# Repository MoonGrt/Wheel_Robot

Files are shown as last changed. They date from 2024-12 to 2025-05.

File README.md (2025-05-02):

**English | [简体中文](README_cn.md)**

[][contributors-url]
[][forks-url]
[][stars-url]
[][issues-url]
[][license-url]

<!-- PROJECT LOGO -->
<br />
<div align="center">
    <a href="https://github.com/MoonGrt/Wheel_Robot">
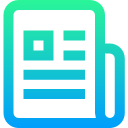
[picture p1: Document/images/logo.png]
    
    </a>
<h3 align="center">Wheel_Robot</h3>
    <p align="center">
    project_description
    <br />
    <a href="https://github.com/MoonGrt/Wheel_Robot"><strong>Explore the docs »</strong></a>
    <br />
    <a href="https://github.com/MoonGrt/Wheel_Robot">View Demo</a>
    ·
    <a href="https://github.com/MoonGrt/Wheel_Robot/issues">Report Bug</a>
    ·
    <a href="https://github.com/MoonGrt/Wheel_Robot/issues">Request Feature</a>
    </p>
</div>

<!-- CONTENTS -->
<details open>
  <summary>Contents</summary>
  <ol>
    <li><a href="#file-tree">File Tree</a></li>
    <li>
      <a href="#about-the-project">About The Project</a>
      <ul>
      </ul>
    </li>
    <li><a href="#contributing">Contributing</a></li>
    <li><a href="#license">License</a></li>
    <li><a href="#contact">Contact</a></li>
    <li><a href="#acknowledgments">Acknowledgments</a></li>
  </ol>
</details>

<!-- FILE TREE -->
## File Tree

```
└─ Project
  ├─ Document
  ├─ Software
  ├─ Tool
  └─ /Hardware/

```

<!-- ABOUT THE PROJECT -->
## About The Project

- [📦 Hardware System Design](#-Hardware-System-Design)
  - [🔋 Power Management Module](#-Power-Management-Module)
  - [🧩 FOC Driver](#-FOC-Driver)
  - [🐞 Link Debugger](#-Link-Debugger)
  - [🧲 Magnetic Encoder](#-Magnetic-Encoder)
- [🔧 Structural Design and Device Selection](#-Structural-Design-and-Device-Selection)
  - [🧱 Housing and Structure](#-Housing-and-Structure)
  - [⚙️ Power System](#-Power-System)
  - [🎯 Sensor Selection](#-Sensor-Selection)
- [💻 Software System Design](#-Software-System-Design)
  - [⚡ FOC Motor Control Subsystem](#-FOC-Motor-Control-Subsystem)
  - [🤖 ROS System Integration](#-ROS-System-Integration)
  - [🌐 Web Console](#-Web-Console)

### Hardware Selection

| Module | Component/Chip Model | Functional Description | Device Parameters |
| --- | --- | --- | ---|
| Master | Raspberry Pi | With ROS, responsible for SLAM algorithms | - |
| | STM32F405 | Dedicated to motor control (FOC, PID) | 180MHz, Cortex-M4 core |
| Sensors | AS5147P | Ultra-high-speed Magnetic Rotary Position Sensors | 16-bit resolution, SSI interface |
| | CMP10A | IMU Sensor | 3-axis gyroscope, 3-axis accelerometer, 3-axis magnetometer and barometer |
| | YDLIDAR X3 | LIDAR | 360° scanning, range 0.12-8m |
| POWER MANAGEMENT | LITHIUM BATTERY | - - | 24V, 3000mAh, XT60 socket |
| | TPS54160 + RT9193/LP5907 | 24V→12V/5V→3.3V Two-stage Buck Regulator | TPS54160-Buck, RT9193-VCC, LP5907-AVCC |
| | FSMD012 | Resettable Fuse - Overcurrent Protection | 50A Peak Current |
| | NCP18XH103F0 | Real-time monitoring of the circuit temperature, to prevent overheating damages | 10kΩ B-value -25°C /100°C-3455K |
| | LM5109B + RTP50W | High Speed Half Bridge Driver Control Dissipation Resistor | 5V-18V Driver + 50W Power Resistor, 2ohm |
| | SS34 | Schottky Diode | 3A, 40V, Low Dropout |
| | SMAJ26CA | TVS Diode, Surge Suppression Protection | 30V, Bi-Directional, 400W |
| | 1812 Capacitor × 10 | Decoupling Filter | 50V, 47µF, Ceramic Capacitor |
| Motor Driver | DRV8301 | Brushless DC BLDC Motor Driver Chip | 4.5V-60V, Peak Current 4A |
| | KNY3406C | Field Effect Tubes (MOSFETs) | Vds=40V, Id=60A, Rds(on)=6mΩ |
| | SG995 | Servo, Position Control | 180° Rotation Angle, Torque `13kg.cm @ 6V` |
| | PM3510 | Platform Brushless Motor | 1250rpm 0.11N.m |

### 📦 Hardware System Design

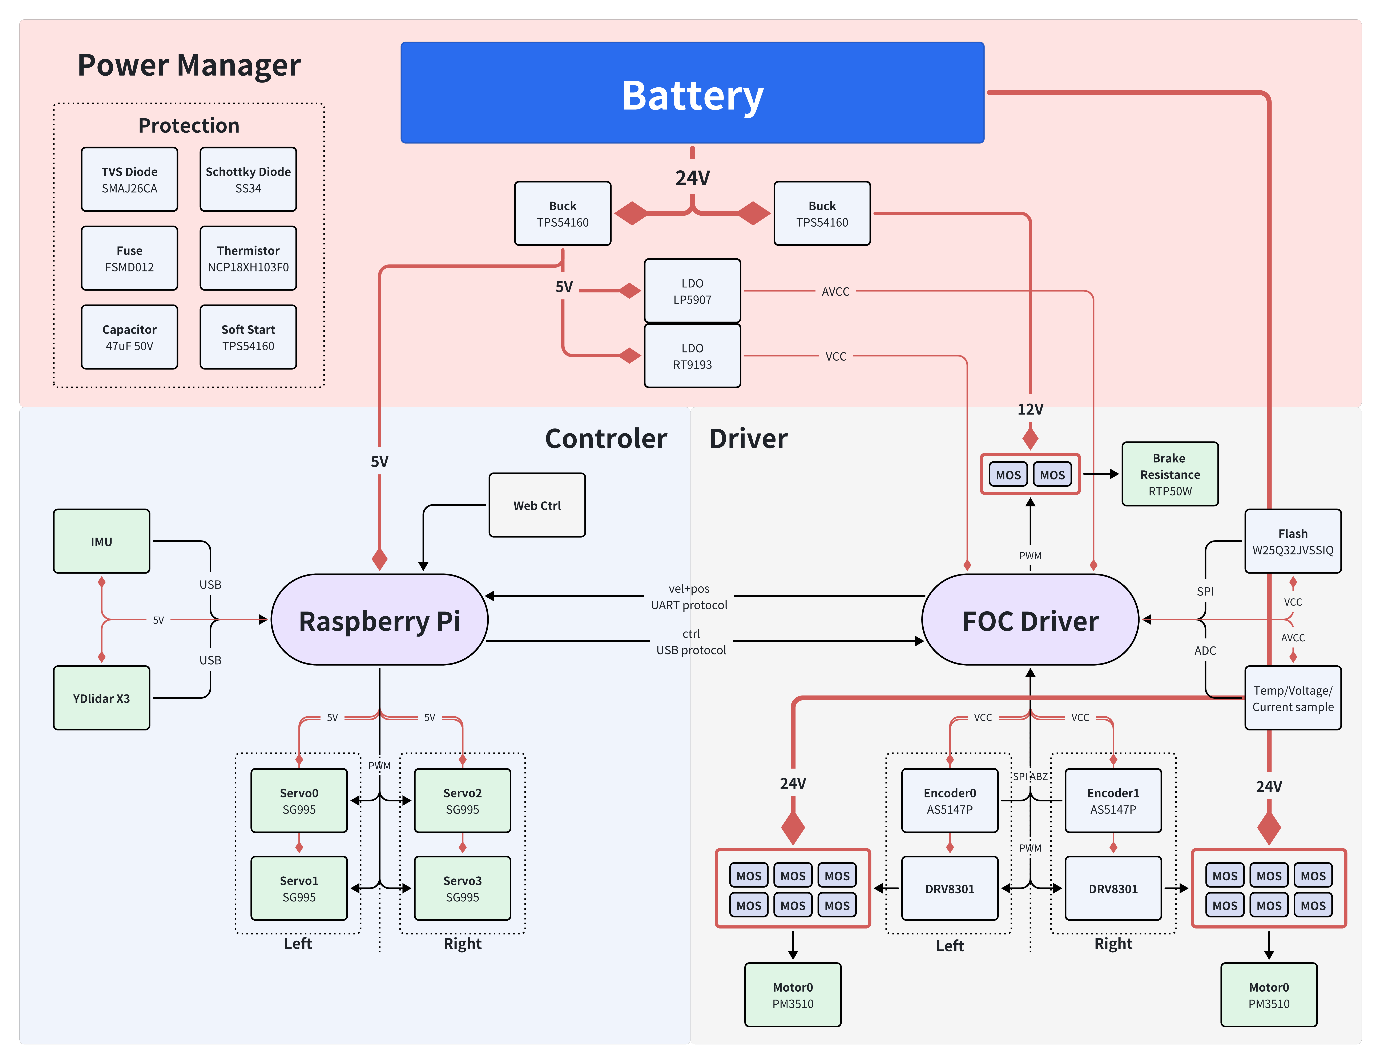
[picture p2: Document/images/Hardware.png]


#### 🔋 Power Management Module

The power management module distributes the battery energy, after buck regulator filtering, to the modules of Raspberry Pi, motor driver, sensors (IMU, Lidar, encoder), power system (BLDC motor, servo), etc., to ensure the power supply of each module operates stably.

- **Battery Management System (BMS)**
  - Uses **24V 3000mAh Li-ion battery pack** (XT60 interface) as the main power source.
    - 29.4V 2A charger
  - Built-in intelligent protection board for stable output and longer life:
  - Overcurrent protection: prevents the battery from discharging too much current
  - Short-circuit protection: the product is automatically protected in the event of a short-circuit
  - Over-voltage protection: prevents the battery from charging and discharging too high a voltage
  - Over-charging protection: prevents the battery from being over-charged
  - Over-discharging protection: prevents the battery from being over-discharged
  - Anti-backlash protection: stops the work automatically in case of reverse plugging
  - 10A Button Switch (main switch: for controlling battery charging/discharging; emergency disconnecting the battery) + 16AWG conductor
  - Soldering part is covered with insulating green oil + Heat-shrinkable tubing/insulation tape is used for connecting part of the conductor

- **Voltage Conversion**
  - **Two-stage Bucking Architecture**:
  - Power Supply 24V: Power supply the BLDC motors, BUCK step-down circuits, power supply voltage acquisition circuits, and other modules directly through the power MOS.
    - First stage: TPS54160 (24V→12V, power supply dissipative resistor; 24V→5V: power supply servo, Raspberry, LDO) (Output current 1.5A, switching peak limiting current 1.7~2.3A)
  - TPS54160 Configuration Reference [Texas Instruments Official Design Tools](https://www.ti.com.cn/ product/cn/TPS54160#tech-docs)
  - Stage 2: RT9193 (5V→3.3V, LDO linear regulator, VCC, power supply MCU, encoder chip, motor driver chip), LP5907 (3.3V→5V, voltage regulator, AVCC, power supply analogue end temperature sampling)
  - **Decoupling filter network**: 10 × 1812 ceramic capacitors (50V/47µF) + 1812 ceramic capacitors (63V/47µF)
  - Changing the capacitor closest to the TVS diode to 63V/47µF prevents the capacitor from breaking down due to the surge phenomenon during power-up.
  - **Isolated Ground** - The analogue/power ground is isolated from the digital ground to avoid signal interference.

- **Circuit Protection Design**
  - **Overcurrent Protection**: FSMD012 self-resetting fuse (48V/40A)
  - **Temperature Monitoring**: 10kohm NCP18XH103F0 thermistor (B-value -25℃/100℃-3455K)
  - **Reverse Connection Protection**: SS34 Schottky diode (40V/3A)
  - **Soft Start Protection **: TPS54160 soft-start setting pin external 6.8n capacitor (the larger the capacitance value, the slower the startup)
  - **Transient Suppression**: SMAJ26CA (reverse cutoff voltage (Vrwm): 26V; clamp voltage: 42.1V; peak pulse current (Ipp): 9.5A), bypass resistor (10Ω)
  - Previously used SMAJ30CA with clamp voltage was about 48.4V, the inrush current was so high that the voltage instantaneously rose above the capacitor breakdown voltage before the TVS reacted, causing the capacitor nearest the TVS to break down. (Battery output voltage is 24V~29V)
  - Previously used 3.3Ω resistor with limited inrush suppression
  - **LM5109B** High Speed Half Bridge Driver + **RTP50W** 2Ω/50W Dissipative Resistor to improve motor system stability.
    - Without power dissipation resistors, excess power is charged back to the supply during deceleration to achieve the desired deceleration torque. If the power supply is not able to absorb this energy (which is usually the case with battery power), the bus voltage will inevitably rise. This may cause damage to the switching power supply. In this design, although battery power is used, RTP50W dissipative resistors are still used to improve the stability of the motor system.
    - The power selection of the power resistor depends on your configuration of the motor and the peak power or average deceleration power generated when the motor decelerates. To be safe, you need to consider the speed of the motor and the current the motor can handle. When braking at maximum speed and maximum motor current, the power dissipated in the power dissipation resistor can be calculated as: P_brake = V_emf * I_motor where V_emf = motor_rpm / motor_kv. In this design, using a PM3510 motor with 1250rpm 45rmp/v 0.93A, P_brake = 1250 / 45 * 0.53 = 25.83W.

#### 🧩 FOC Driver

The dual motor FOC driver solution based on STM32F4 series microcontroller supports brushless motor vector control with integrated encoder interface, HALL sensors, CAN communication and multiple peripheral interfaces. It combines a powerful microcontroller with a dedicated driver chip to achieve accurate and highly responsive closed-loop control.

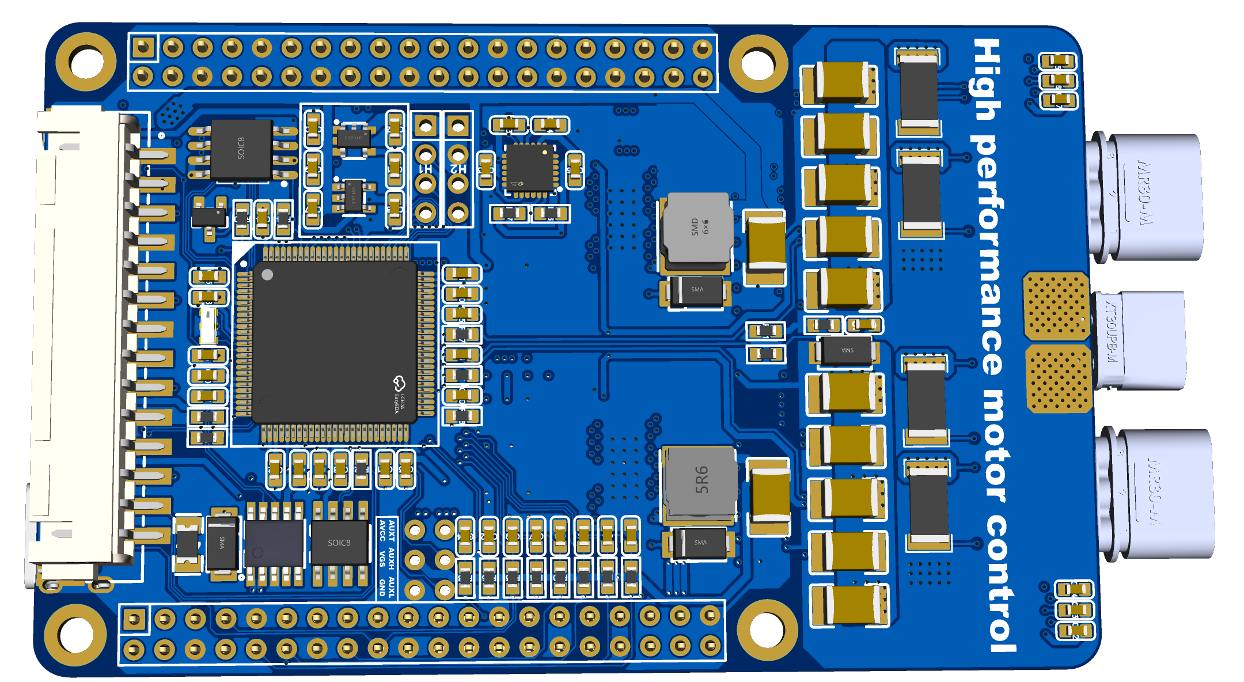
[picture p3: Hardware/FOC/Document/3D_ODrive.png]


- **Main Functional Modules**
  - **Master Control Unit**
    - **Kernel Chip**: STM32F405VGT6 (ARM Cortex-M4 core, 168MHz, 1MB Flash, 128KB SRAM)
    - **Clock System**: 8MHz Crystal Oscillator
    - **Debug Interface**: SWD (SWCLK/ SWDIO)
    - **Memory**: W25Q32JV SPI Flash
    - **Layer structure**: SIG-PWR-GND-SIG
      - Top layer: Signal layer + copper-laying GND
      - Inside layer 1: small amount of signals + copper-laying VCC
      - Inside layer 2: Power supply layer with copper-laying GND
      - Bottom layer: Signal layer with copper-laying GND
  - **Motor Driver Module**
    - **Driver chip**: DRV8301DCDC **: DRV8301DCAR × 2, support dual motor control
    - **Power Stage**:
      - Pre-Drive Circuit: KNY3406C MOSFET × 12
      - Current Sampling: 0.5mΩ Low Side Resistor
      - Provide Deadband Control, Programmable Gate Drive Capability
  - **Protection Design**:
    - SMAJ30CA TVS Diode
    - 2.2Ω Gate Drive Resistor
  - **Sensor and Feedback**
    - **Position Detection**:
      - Encoder Interface: ENC_A/B/Z signals
      - HALL Sensor Interface: GH/GL/SH/SL signals
    - **Temperature Monitoring**: M0_TEMP/M1_TEMP/AUX_TEMP thermistor interface
    - **Voltage Monitoring**:
  - **Communication Interfaces**
    - **CAN Bus**: SN65HVD232DR transceiver
    - **USB**: CH340K USB to Serial
    - **Expansion Interface**:
      - SPI: MOSI/MISO/SCK/CS
      - I2C: SCL/SDA
      - UART: TX1/RX2
  - **Power Management**
    - **Input Power**:
      - Battery Input: 24V DCBUS BUCK Buck circuit
      - USB power supply: Type-C interface
    - **Voltage regulator circuit**:
      - 3.3V LDO: LP5907MFX-3.3
      - 5V LDO: RT9193-33GB
  - **Filtering design**:
    - Multi-stage LC filtering
    - Ceramic capacitor array

- **Key design features**
  - **Dual-motor architecture**: two independent DRV8301 driver chips Enables dual FOC control
  - **Precision Sampling**:
    - 40nF differential capacitor for current sampling filtering
    - 18kΩ/133kΩ precision resistor network
  - **Safety Protection**:
    - NFAULT Fault Detection Circuitry
    - Dead Time Control (DTC=150kΩ)

- **Physical interface**

<div style="width: auto; display: table; margin: auto;">

| Interface Type | Function Description |
| ---|---|
| FPC-6 P | Download, Debug Interface |
| 2*20 row mother | Raspberry Pi Interface |
| Type-C | USB Communication |

</div>

- **PCB Design Features**
  - Layered Ground Plane: PGND (Power Ground)/AGND (Analogue Ground)/GND (Digital Ground) Separation
  - High Current Path: 1oz Copper Thickness 20~50mil Wide, Copper Cladding to Enhance Heat Dissipation
  - Test Points: TP1-TP6 for easy measurement of critical signals

- **Version**

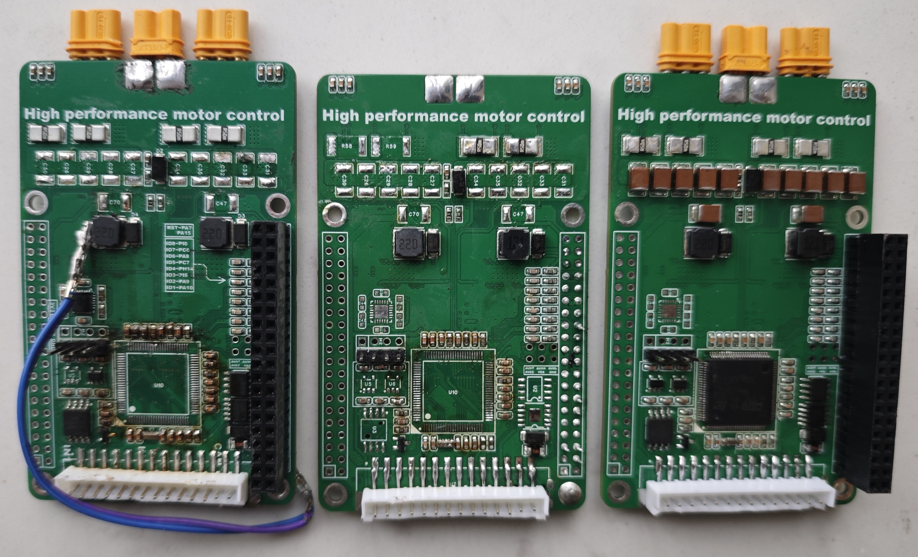
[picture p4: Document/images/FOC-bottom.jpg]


#### 🐞 Link Debugger
This circuit implements the debugger function based on STM32F103CBT6 microcontroller, compatible with STLink V2 and DAPLink firmware, supporting Type-C USB interface and SWD/JTAG debugging. Main purpose: miniaturisation (11mm x 26mm), portability (combining SWD and UART with FPC-6 interface, easy to connect the debugger to the master instead of connecting them one by one with Dupont cable).

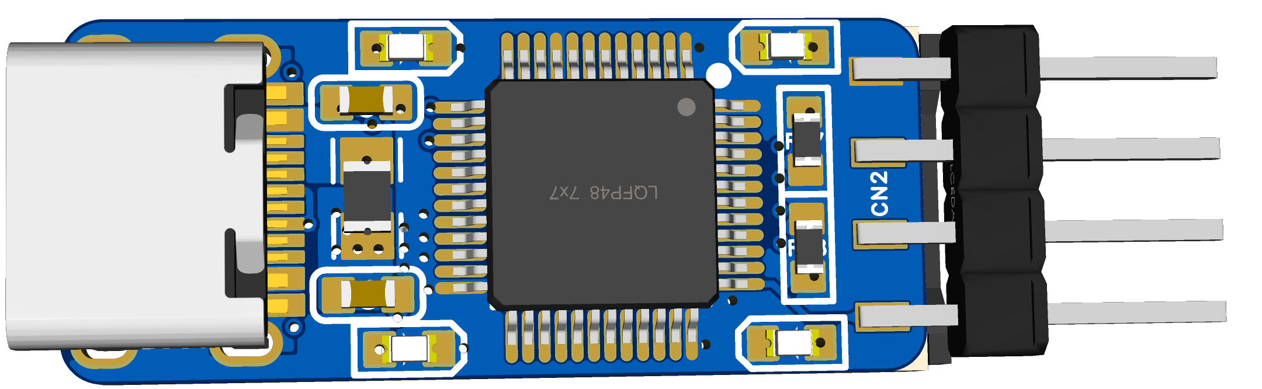
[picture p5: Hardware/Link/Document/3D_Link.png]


- **Main Module**
  - **Power Supply Module**
    - **LDO Circuit**: 5V to 3.3V (Model 662K)
    - **Filter Capacitor**: Input: 1µF; Output: 100nF
    - **Power Indicator**
    - **Power Supply Protection**: BSMD0805-100-6V, PPTC Self-Recovering Fuse for overcurrent prevention.
  - **Master Chip**
    - **Ctrl Unit**: STM32F103CBT6 (72MHz, 128KB Flash, 64KB SRAM)
    - **Clock Source**: 8MHz crystal with 22pF load capacitor
  - **Peripheral Circuitry**
    - **Reset Circuitry**: 10kΩ Pull-up Resistor + 100nF Filter Capacitor
    - **LEDs Indicator**: Power indicator, debug status indicator, serial communication indicator
    - **Power Acquisition**: Acquisition of half of the voltage value of the power supply to the ADC input to the MCU
  - **Connector**
    - **USB Interface**: Type-C USB interface
    - **FPC Interface**: 6Pin, UART+SWD interface,
    - **Debug Interface**: 4Pin SWD standard interface for firmware burning for debugger
- **Special Design**
  - **DTC143ZCA**: digital transistor: used to detect whether VBUS is valid or not, so as to control the USB_RENU signal
  - Resistors such as R10, R15, and R13 are used in conjunction with Q1, to form a simple voltage detection and pull-down control. When VBUS detects 5V, Q1 conducts and USB_RENU is pulled high (or low), prompting the MCU for ‘USB insertion detection’.

#### 🧲 Magnetic Encoder
Non-contact encoder with high precision magnetic rotary position sensor design, compatible with AS5147P, AS5047P, suitable for motor position detection, supports multiple output modes, with anti-interference and high temperature working characteristics.AS5147P comes with an LDO, so no extra LDO is needed.(Main function: connect/ (Main functions: connecting/welding encoder chip, supplying power to encoder chip - power protection, providing encoder interface to master control for connection)

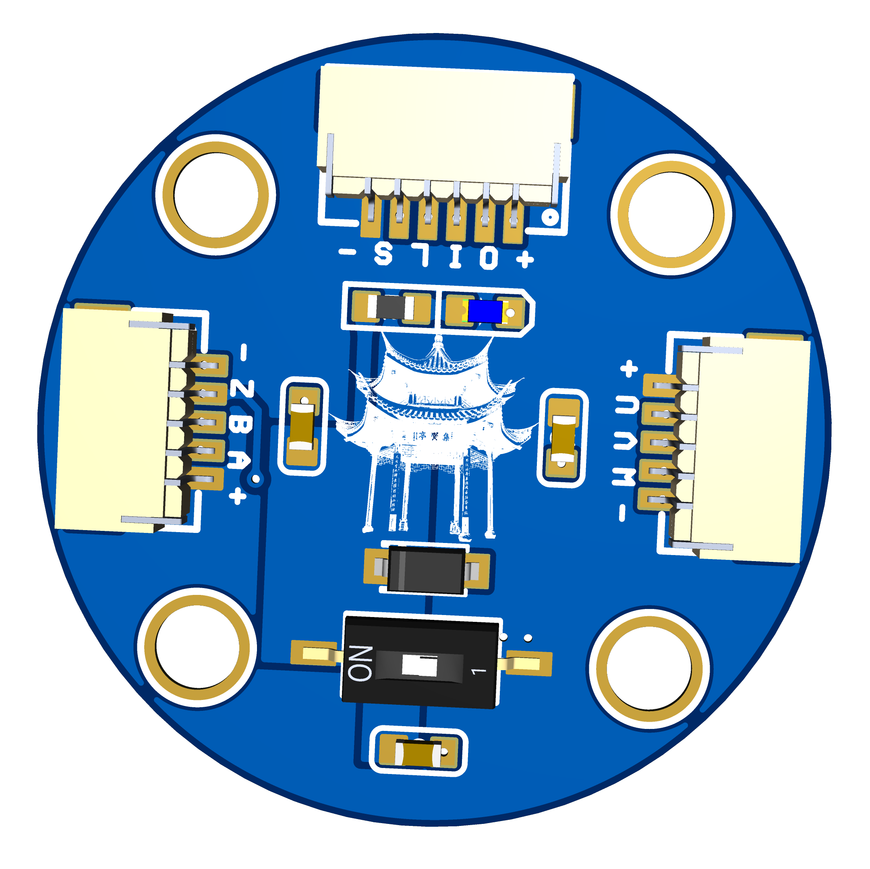
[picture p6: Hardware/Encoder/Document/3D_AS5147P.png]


- **Core Features**
  - **Resolution**: 14-bit absolute position output (0.022° accuracy)
  - **Interface Support**:
    - SPI (SCK/SDI/SDO/CS)
    - ABZ
    - UVW
    - PWM Pulse Width Modulation
  - **Operating Voltage**: 3.3V/5V Wide Voltage Compatible
    - Provide DIP switches for user to select input voltage mode
  - **Mechanical characteristics**: 360° contactless rotation detection
- **Hardware Design Points**
  - **Anti-Interference Design**
    - Power Filtering: 100nF ceramic capacitors in parallel
    - Signal Isolation: Magnetic Grids are laid out orthogonally to PCB alignment
  - **Protection Design**
    - SMFJ5.0A: Static and Surge Protection (TVS/ESD)
    - LEDs: Indicates the power supply status
  - **Size Design**: Combined with the Mechanical design, to be embedded in the housing, size 26mm

---

### 🔧 Structural Design and Device Selection

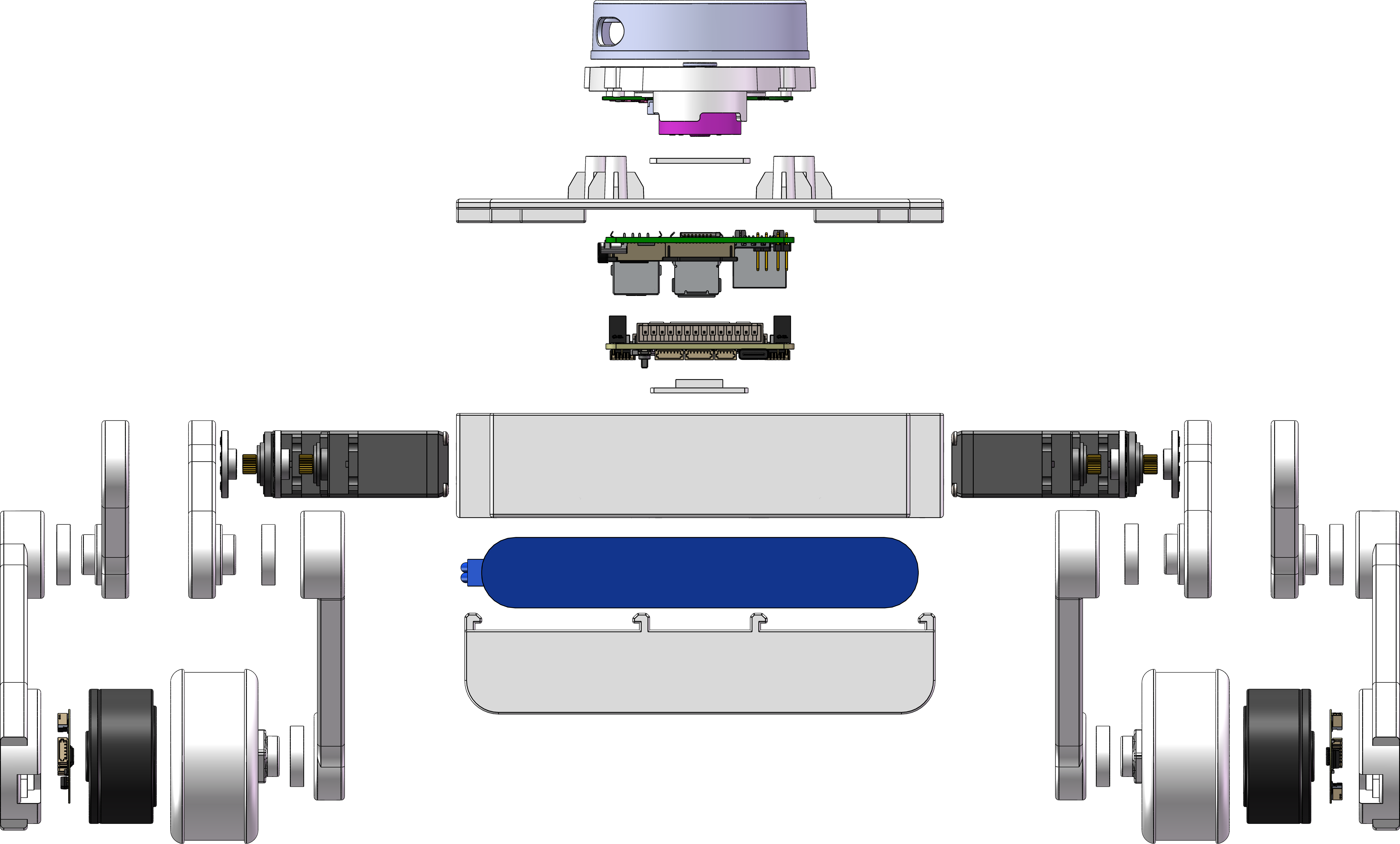
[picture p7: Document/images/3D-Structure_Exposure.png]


#### 🧱 Housing and Structure
- **3D printed housing**
  - Structure: modular assembly with quick release interface for easy maintenance and function expansion.
  - Internal reserved battery compartment, circuit board fixing holes, heat dissipation design.
  - Reserve 0.2mm tolerance between structural parts
  - Base:
    - Material: X resin (large parts, cost saving)
    - Thickness: 3mm
    - Structure:
      - Middle assembly tabs to fix the main control board and driver board
      - Fixed servos on both sides
      - Front and back openings to expose the main control board, driver board interface, and knob switch fixing holes.
      - Bottom: Sinking in the middle to fix the IMU module; both sides are reserved for the slots of the Battery Case.
      - Reserved threaded holes and countersunk holes for bolts
  - Cover:
    - Material: X resin (large part, cost saving)
    - Thickness: 3mm
    - Structure:
      - Base fixing holes
      - Assembly tabs to fix ydlidar, sunk in the middle to fix ydlidar driver board
      - Reserved threaded holes and countersunk holes for bolts
  - Battery Case:
    - Material: X resin (large part, cost saving) - Thickness: 3mm Cost saving)
    - Thickness: 3mm
    - Structure:
      - middle sunken to fix the battery
      - both sides partly upward to form the snap with Base
      - front and back right upper corner open hole, reserved for battery cable
      - reserved threaded holes, countersunk holes for bolts for connecting
  - Arm:
    - Material: PLA
    - Thickness: 8mm
    - Structure:
      - fix the servo and Motor Case
      - Arm inter-bearing connecting
      - reserved space for motor cables, encoder cables Space
      - Distance between control motor radial magnet and encoder (<1mm)
      - Reserved threaded holes, countersunk holes for bolts for connection
  - Motor Case:
    - Material: PLA
    - Thickness: 3mm
    - Structure:
      - Fixed Motor, Magnetic Encoder
      - Reserved space for bearings
      - Outer recessed, reserved space for rubber ring
      - Reserved threaded holes, countersunk holes for bolts for connection

#### ⚙️ Power System

- **Brushless DC motor**
  - Model: **PM3510**
  - Parameters: 1250rpm, 0.11N-m, 45 rmp/v, Driver chip DRV8301.
  - Note:
  - Motor radial magnet needs to be replaced (the original motor radial magnet has a poor magnetism, which results in a noisy encoder).
    - When installing a stronger encoder magnet, the distance between the magnet and the encoder in the mechanical design should be considered.
- **Servo**
  - Model: **SG995**
  - Parameters: 20ms, 180°rotation angle (500-2500), 13kg-cm Torque (@6V), 100mA.
  - Note:
    - Pay attention to the initial angle when installing, to avoid the wrong rotation direction.

#### 🎯 Sensor Selection

##### **AS5147P High-Speed Rotary Position Sensor**

- **Product Overview**
  - **AS5147P** is a CMOS technology-based 14-bit, high-resolution, axial-magnetic rotary position sensor designed for high-speed applications up to **28,000 RPM**, providing complete ** 360° absolute angle measurement**. It incorporates advanced **Dynamic Angular Error Compensation (DAEC™)** technology, which effectively suppresses angular errors caused by system delays to achieve a virtually **zero delay output**.
  The AS5147P also features a **12-bit incremental binary output interface (ABI)** with a resolution of up to **4096 steps/1024 pulses per revolution**, which is suitable for encoder systems. Through the standard **4-wire SPI interface**, the master device can read the high-precision angular information output from the sensor, and supports programmable non-volatile configurations without the need for an external programmer.

- **Key features**

  <div style="width: auto; display: table; margin: auto;">

  | Feature Category | Description |
  |--------------------|-------------------------------------------------------------|
  | **Resolution** | 14-bit Absolute Angle-SPI<br>12-bit Incremental Encoding (ABI: 1024/2048/4096) |
  | **Speed Support** | Up to **28,000 RPM** for high speed rotation detection |
  | **Output Interfaces** | SPI, ABI, UVW commutation signals, PWM Duty Cycle encoded outputs |
  | **Dynamic Angle Compensation** | DAEC™ Dynamic Angle Error Compensation (for SPI, ABI, UVW outputs, enhancing real-time) | | **Dynamic Angle Compensation** | DAEC™ Dynamic Angle Error Compensation (for SPI, ABI, UVW outputs, enhancing real-time) |
  | **Anti-Interference Capability** | Suppresses uniform stray magnetic field interference and improves system stability |
  | **Non-Volatile Configuration** | SPI interface programmable, no need for dedicated programmer |
  | **Self-Diagnostic Functions** | Detects magnetic field strength abnormalities (too strong/too weak/absent), device status abnormalities, etc. |
  | **Interpolation and Signal Integrity** | Interpolates missing ABI pulses at high speeds to ensure resolution and signal continuity. Interpolation and Signal Integrity**| Interpolates missing ABI pulses at high speeds to ensure resolution and signal continuity.

  </div>

  - **Technical Principles and Architecture** 
    - The AS5147P utilizes an array of **Hall effect sensors** that convert magnetic field components into voltage signals by sensing the magnetic flux density perpendicular to the chip surface. After amplification and filtering by an analog front end (AFE), these signals are fed into an analog-to-digital converter (ADC) and then processed by the CORDIC algorithm to accurately calculate the angle and amplitude of the magnetic vector. In addition, the AS5147P 
      - **Automatic Gain Control (AGC)** mechanism: real-time adjustment of the front-end gain to adapt to changes in magnetic field and temperature 
      - **CORDIC Algorithm Module**: calculates the angle of rotation and the amplitude of the magnetic field 
      - **Interpolation Mechanism**: completes the missing pulse of the ABI at high speeds to ensure the continuity of the output signals 
    - The AS5147P has a **Dynamic Angular Error Compensation (DAEC™)** function. The AS5147P features **Dynamic Angle Error Compensation (DAEC™)**, which improves real-time performance of the SPI, ABI, and UVW outputs by estimating the time delay during angle measurements and predicting and compensating for the angular output error accordingly. This compensation is particularly effective at constant speeds.

##### **YDLIDAR X3 LIDAR** 

The YDLIDAR X3 is a high-performance, compact 2D LiDAR (LiDAR) product that utilizes the principle of triangulation and combines advanced optical, electrical and algorithmic design to enable **360-degree omni-directional environmental scanning and high-precision distance measurement**.

- 🌐 Core Functions Overview 
  - 🔄 **360° Omni-directional Scanning and Distance Measurement** 
  YDLIDAR X3 is equipped with a rotary motor, which is capable of realizing **complete 360-degree rotations in the horizontal plane**, and real-time outputting the distance measurement data of the corresponding angle in each rotation to form a high-density 2D point cloud map. This means that it is capable of **panoramic perception of its surroundings** and can obtain complete spatial information without moving the platform itself.
  - 🎯 **High-precision and high-frequency ranging performance** 
  The radar achieves a ranging capability of up to **4,000 times per second** (typical) through the mechanism of transmitting high-frequency laser pulses and receiving them as echoes, ensuring smooth, detailed perception even in fast-moving environments.
    - **Typical ranging accuracy: ±2cm (≤1m)** 
    - **Relative error: minimum 1%, and within 3.5%~5% at long distances** 
  - ☀️ **Strong resistance to interference from ambient light** 
  The YDLIDAR X3 possesses good resistance to interference, and can work stably under natural light or artificial light. Whether it is bright daylight exposure or indoor lighting strobe, it can maintain stable output to ensure the reliability of ranging data.
  - 🔋 **Low power consumption, small size, long life** 
  The product design focuses on energy saving and portability, with low energy consumption operating characteristics, and adopts a long-life rotating structure and optoelectronic components, which is suitable for long-term deployment in a variety of smart devices.
  - ⚙️ **Motor speed is adjustable to suit different needs** 
  Users can adjust the scanning frequency from **5Hz to 10Hz** according to the application needs, balancing the measurement accuracy and real-time performance. For example: 
    - **5Hz: the angular resolution can be up to 0.6°**, suitable for scenarios requiring high accuracy (e.g. map building) 
    - **10Hz: the angular resolution is 1.2°**, which is more suitable for tasks requiring higher real-time performance (e.g. obstacle avoidance) 

- ⚙️ Performance Parameters

  <div style="width: auto; display: table; margin: auto;">

  | Item | Minimum | Typical | Maximum | Unit | Remarks | 
  | ------------------ | -------- | -------- | -------- | ------ | ---------------------------- | 
  | Ranging Frequency | / / | 4000 | / | Hz | Ranging per second max. 4000 times | 
  | Scanning Frequency | 5 | 8 | 10 | Hz | Motor Adjustable | 
  | Ranging Range | / | 0.12/8 | / | m | 10%/80% Reflective | 
  | Scanning Angle | / | 0-360 | / | ° | Rotation of 360° | 
  | Absolute Error of Ranging | / | 2 | / | cm | ≤1m range | 
  | Relative Error | / | 1% | 5% | / | Maximum Relative Error in 8m distance | 
  | Angle Resolution | 0.6 | 0.96 | 1.2 | ° | corresponds to 5Hz/8Hz/10Hz respectively | 
  | Pitch | 0.25 | 1 | 1.75 | ° | Bound Angle control range |

  </div>

##### **CMP10A-IMU Inertial Measurement Unit**

CMP10A is a high performance 3D motion attitude measurement system based on MEMS technology. It contains three-axis gyroscope, three-axis accelerometer, three-axis electronic compass motion sensor and barometer. Through the integration of various high-performance sensors and the use of self-developed attitude dynamics core algorithm engine, combined with high-dynamic Kalman filter fusion algorithms, to provide customers with high-precision, high-dynamic, real-time compensation of the three-axis attitude angle, through the flexible choice of configuration of various types of data, to meet the different application scenarios.

- **Product Features**
  - The module integrates high-precision gyroscopes, accelerometers, geomagnetic field sensors and barometers, and adopts a high-performance microprocessor and advanced dynamics solving and Kalman dynamic filtering algorithms, which are able to quickly solve the current real-time motion attitude of the module.
  - The advanced digital filtering technology can effectively reduce the measurement noise and improve the measurement accuracy.
  - Module internal integrated attitude solver, with dynamic Kalman filtering algorithm, can accurately output the current attitude of the module in the dynamic environment, attitude measurement accuracy of static 0.05 degrees, dynamic 0.1 degrees, the stability is very high, the performance is even better than some professional inclinometer.
  - The Z-axis heading angle is fused with geomagnetic sensor filtering, which solves the cumulative error caused by the drift of the gyroscope integral in the 6-axis algorithm, and can output the heading angle data stably for a long time. Note: It needs to be calibrated before use due to magnetic field detection, and it needs to be kept at least 20cm away from magnetic interference areas, electronic devices, magnets, speakers and other hard magnetic objects.
  - Module comes with internal voltage stabilisation circuit, working voltage 3.3~5V, pin level compatible with 3.3V/5V embedded systems, easy to connect.
  - Supports both serial and IIC digital interfaces. Convenient for users to choose the best way to connect. Serial rate 4800bps~921600bps adjustable, IIC interface support full speed 400K rate.
  - Maximum 200Hz data output rate. Output content can be freely selected, output rate 0.2 ~ 200Hz adjustable.

- **Sensor parameter indicators**

  <div style="width: auto; display: table; margin: auto;">

  | Sensor Type | Parameters | Conditions | Typical |
  | ------------ | ------------ | -------------------- | -------------------------- |
  | Accelerometer | Range | | ±16g |
  | | Resolution | ±16g | 0.0005 (g/LSB ) |
  | | RMS Noise | Bandwidth = 100Hz | 0.75~1 mg-rms |
  | | Stationary Zero Drift | | Horizontal Positioning | ±20~40 mg |
  | | Temperature Drift | -40°C ~ +85°C | ±0.15 mg/°C |
  | | Bandwidth | | 5~256 Hz |
  | Gyro Gauge | Range | | ±2000 °/s |
  | | Resolution | ±2000 °/s | 0.061 (°/s)/LSB |
  | | RMS Noise | Bandwidth=100Hz | 0.028~0.07 (°/s)-rms |
  | | Stationary Zero Drift | Horizontal Placement | ±0.5~1 °/s |
  | | Temperature Drift | -40°C ~ +85°C | ±0.005~0.015 (°/s)/°C |
  | | Bandwidth | | 5~256 Hz |
  | Magnetometer | Range | | ±2 Gauss |
  | | Resolution | ±2 Gauss | 0.0667 mGauss/LSB |
  | Barometer | Range | | 300~1100 hPa |
  | | RMS Noise | Standard Mode | 0.5 Pa-RMS |
  | | Relative Accuracy | | ±0.06 hPa |

  </div>

#### **structural connections**
bearings rolled tape insulating tape wires conductors bolts nuts rubber rings (tyres) 502 glue

---

### 💻 Software System Design

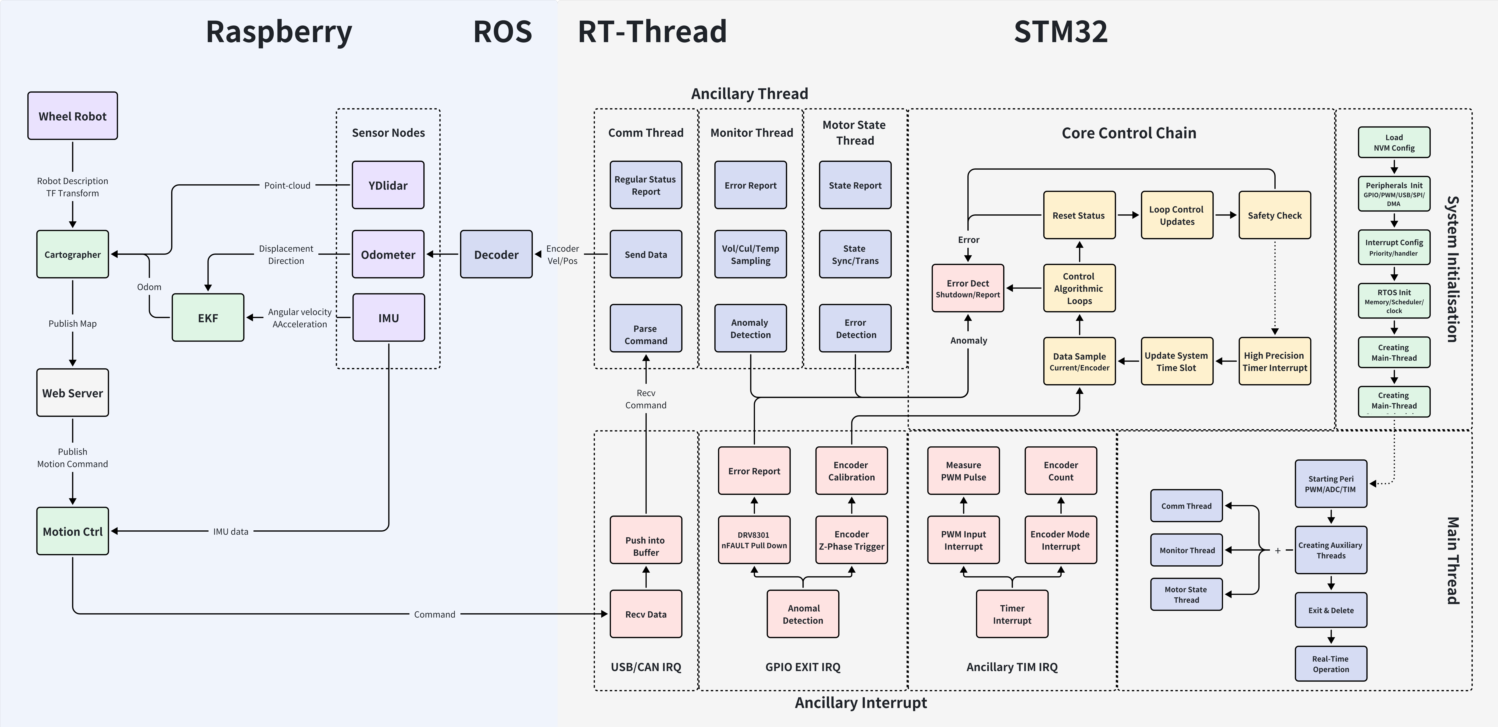
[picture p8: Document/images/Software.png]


#### ⚡ FOC Motor Control Subsystem

##### RT-Thread RTOS
Realisation of task isolation: control thread, current sampling thread, communication thread run independently;

```mermaid
graph TD

    A[System boot] --> B[Load configuration parameters in NVM]
    B --> C[System initialisation]
    C --> C1[Initialise peripherals<br>GPIO/PWM/USB/SPI/DMA...]
    C --> C2[Interrupt Configuration<br>Priority Setting/Register Handler Functions/Initiate Interrupts]
    C --> C3[RTOS Initialisation<br>Memory/Scheduler/Clock...]

    C3 --> D[create main thread]
    D --> E[start scheduler]
    E -.-> F[Main thread execution]
    F --> F1[Start peripherals<br>PWM/ADC/TIM]
    F1 --> F2[Create auxiliary thread]
    F2 --> F2a[Communication processing thread]
    F2 --> F2b[System monitoring thread<br>Analog acquisition/status monitoring]
    F2 --> F2c[Motor status management thread]
    F2 --> G[Exit and delete main thread]

    G --> H[enter real-time running state]

    %% Real-time thread section
    subgraph Real-time running status
        H1[Communication thread]
        H1 --> H1a[Periodic status report]
        H1 --> H1b[USB/CAN interrupt receive command]
        H1 --> H1c[UART polling receive command]
        H1b --> H1d[Receive and parse external control command]
        H1c --> H1d
        H1d --> H1e[Update control target]
        H1c --> H1f[UART polling to send data<br>motor speed/position]

        H2[Monitoring thread]
        H2 --> H2a[Acquire system status<br>temperature/voltage/error signals]
        H2a --> H2b[Abnormality detection]

        H3[Motor status thread]
        H3 --> H3a[Periodic refresh<br>status information for each axis]
        H3a --> H3b[Synchronise current control state<br> operating mode/feedback variables]
        H3b --> H3c[Forward error messages]
    end

    %% Control Chain (driven by hardware timers & interrupts)
    subgraph Control Chain Execution - Core Timer Interrupts
        T1[High Precision Timer Interrupt<br>Control Cycle Trigger] --> T2[Updates System Time Slot]
        T2 --> T3[Software Triggered Control Interrupt<br>Scheduling Control Calculation Flow]
        T3 --> T4[Trigger Sampling & Data Acquisition<br>Current/Encoder /sensor data]
        T4 --> T5[Execute real-time control algorithm loop<br>position/velocity/current]
        T5 --> T6[Reset state & check safety conditions]
        T6 --> T7[Execute closed-loop control update<br>State estimation/PID tuning/PWM update]
        T7 --> T8[Verify cycle integrity/safety check]
        T5 -->|Anomaly detection| D1[interrupt trigger protection<br>shutdown/error reporting]
        T8 -->|anomaly detection| D1
    end

    %% Auxiliary Interrupt
    subgraph Auxiliary Interrupt
        U1[USB/CAN communication interrupt]
        U1 --> U2[Receive command data]
        U2 --> U3[Write data queue]

        G1[GPIO EXIT interrupt]
        G1 --> G2[Detect fault signal]
        G2 --> G3[DRV8301 Fault interrupt... <br>nFAULT pull down...] --> G3a[power down/up error]
        G2 --> G4[encoder Z phase interrupt<br>] --> G4a[encoder calibration] --> T4

        E1[auxiliary TIM interrupt]
        E1 --> E2[encoder interrupt] --> E2a[record encoder edge] --> T4
        E1 --> E3[PWM capture interrupt] --> E3a[read PWM signal Width] --> T4
    end

    %% Interlink
    H1e --> T5
    H2b -->|Exception Feedback| D1
    H3c -->|Error Feedback| D1
    G3a -->|DRV8301 Failure| D1
    U3 -->|Instruction Queue| H1b

    %% Style definitions
    classDef init fill:#CDEDF6,stroke:#2B7A78,color:#17252A;
    classDef thread fill:#E6F7D9,stroke:#4CAF50,color:#1B5E20;
    classDef runtime fill:#FFF3CD,stroke:#FFC107,color:#7F4E00;
    classDef control fill:#E1D5E7,stroke:#9C27B0,color:#4A148C;
    classDef interrupt fill:#FFE5B4,stroke:#FF9800,color:#E65100;
    classDef error fill:#FADBD8,stroke:#C0392B,color:#641E16;

    %% Category labelling
    class A,B,C,C1,C2,C3,D,E init
    class F,F1,F2,F2a,F2b,F2c,G,H,H1,H2,H3,H1a,H1b,H1c,H1d,H1e,H1f,H2a,H2b,H3a,H3b,H3c thread
    class T1,T2,T3,T4,T5,T6,T7,T8 control
    class U1,U2,U3,G1,G2,G3,G3a,G4,G4a,E1,E2,E2a,E3,E3a interrupt
    class D1 error
```

- 🟦 **Initialisation phase**
  - Starting from `System Startup`:
  - **Load Configuration Parameters from NVM**: Used to load previously saved system parameters such as motor configurations, calibration data etc.
  - **System initialisation**: divided into three key sections:
    - `GPIO/PWM/USB/SPI/DMA` and other peripherals initialisation.
    - Interrupt configuration, including interrupt priority setting, registering ISR.
    - RTOS (Real-Time Operating System) initialisation, starting the scheduler, memory stacks, etc.
  - Finally, creating the main thread and starting the scheduler.
- 🟩 **Main thread running logic**
  - **Starting peripherals**: e.g. PWM outputs, current sampling ADCs, timers, etc.
  - **Create three auxiliary threads**:
    - **Communication processing threads**: USB/CAN/UART receive, status upload.
    - **System monitoring threads**: such as temperature, voltage monitoring and fault detection.
    - **Motor status management thread**: periodic update of the operating status of each axis.
  - The main thread exits when the task is completed and the system enters the real-time operation state.
- 🟨 **Real-time operation phase**
  - **Communication thread (H1)**
    - Handles USB/CAN/UART commands.
    - Report status data.
    - Parses control commands, updates control targets, and enters the control chain (associated with the control core).
  - **System Monitoring Thread (H2)**
    - Periodically collects temperature, voltage, error flags, etc. Performs anomaly detection.
    - Performs anomaly detection and reports to `Error Handling D1` when problems are found.
  - **Motor Status Management Thread (H3)**
    - Periodically refreshes motor status and feeds back to the control system.
    - Transmits operating mode changes, error messages, etc.
- 🟪 **Core Control Chain**: This is the ‘heart’ of the control system, driven by the timer interrupt:
  - High-precision timer interrupt triggered → control cycle starts.
  - Start the soft interrupt to execute the control logic:
    1. **Sampling data**: Read encoder, current sensor, etc. 2.
    2. **Execute control algorithm**: including closed-loop control of position, speed, current.
    3. **Update PWM**: output to motor drive.
    4. **Cycle safety check and status reset**.
  - If an abnormality is detected, it will immediately enter `Error Interrupt Processing` and shutdown/protection.
- 🟧 **Auxiliary Interrupt Module**: interrupt events that supplement the control logic:
  - **Communication Interrupts**
    - Receives USB/CAN external control data, writes it to the command queue, and later parses and executes it by the communication thread.
    - UART DMA interrupt
  - **GPIO interrupt**
    - Detects e.g. `DRV8301 nFAULT` fault signal.
    - Z-phase encoder interrupt for one-time calibration (e.g., home alignment).
  - **Timer interrupt**
    - Encoder edge capture, PWM width capture for RPM and position measurement.

- Note:
  - Note why the thread performs the control and uses a timer interrupt?

##### PID Regulation Flow - FOC Algorithm

The control algorithm uses a three-level closed-loop architecture with position control, speed control and current control in order from top to bottom. The control thread receives new input commands, reads the encoder and current sensor feedback, executes each level of the PID algorithm, and updates the control output in each control cycle. The entire process is embedded with measures such as anti-integral saturation, limiting, gain scheduling, and anti-groove calibration to ensure high accuracy and robustness.

- **Overall flow of the control chain**
  ```mermaid
  graph LR
    A[Incoming target command from host computer<br>Position/Speed/Current] --> B[Input processing & trajectory planning<br>Multi-mode filtering/Trap Traj / Mirror etc.]
    B --> C[Position Loop: compares the target position with the current encoder or estimate and calculates the positional error]
    C --> D[Generate additional speed expectations based on P-control and anti-alveolar compensation etc.]
    D --> E[Speed loop: compare desired speed from position loop with actual speed to calculate torque or current expectations using PI structure]
    E --> F[Conversion: torque expectation is calculated from motor output via PI structure speed expectation]
    D --> E[Velocity loop: compare desired speed from position loop output with actual speed<br>Calculate torque or current expectation using PI structure]
    E --> F[Conversion: torque expectation is converted to current expectation by motor parameters and torque constants<br>ACIM-type motors need to be scaled by flux]
    F --> G[Current Loop: access to the d-q coordinate system, control current error using the PI algorithm PI algorithm to control current error]
    G --> H[Voltage command calculated and converted by SVPWM module to generate PWM waveform]
  ```

  Of these:
  - **Input Processing** Updates the internal setpoint according to the different input modes (Passthrough, speed/torque ramping, trajectory planning, etc.) and filters the loop bandwidth, limits, etc.
  - **Position loop** In position control mode, only proportional feedback (pos_gain) is used in conjunction with loop drift correction, notch compensation, etc.
  - **Velocity loop** In addition to multiplying the velocity gain (vel_gain) to obtain a preliminary torque command, an integral term (vel_integrator_torque_) is introduced for error accumulation, and windproof control (gain scheduling and anti-saturation measures) is used.
  - The **current loop**, on the other hand, performs PI modulation of the d-q current error within the Field Oriented Control module, with the integral state limited by the saturation condition of the modulation vectors and combined with feed-forward terms (e.g., reverse potential, R/L feed-forward) to guarantee the system response.

- **Schematic of control chain operation**
  The interaction between the control thread and the peripherals and ADC/FOC interrupts can be summarised as:

  ```mermaid
  sequenceDiagram 
    participant host computer 
    participant communication thread 
    participant control thread 
    participant ADC/FOC interrupt 
    participant encoder 

    host computer->>communication thread: sends target commands (JSON / other formats) 
    communication thread->> Control thread: update input setpoints (position/velocity/torque) 
    Control thread->>Encoder: get position, velocity data (including PLL or encoder estimation) 
    Control thread->>Control thread: preprocessing, trajectory planning according to input mode 
    Control thread->>Control thread: [Position Loop] calculate position error, update vel_ setpoint Control thread->>Control thread: [Position loop] calculate position error, update vel_ setpoint Control thread->>Control thread: [Position loop] calculate position error, update vel_ setpoint setpoint 
    Control thread->>Control thread: [Velocity loop] Calculate velocity error, accumulate acceleration integral, generate torque (current) expectation 
    Control thread->>ADC/FOC interrupt: update current setpoint to FOC module 
    ADC/FOC interrupt-->>Control thread: collect feedback current, trigger current loop PI regulation (FOC) 
    ADC/ ADC/FOC interrupt-->>PWM driver: Generate PWM waveform according to the voltage command from FOC module.

  ```

  In this process:
  - **Input Processing**: not only includes direct setpoint transmission, but also includes various logics such as filtering, slope updating, Trap Traj interpolation, mirror mode, etc.
  - **Feedback from each link**: Position and speed errors affect low and medium frequency control respectively, while the current loop operates at higher frequencies to ensure timely response of the entire closed loop.
  - **Error protection and monitoring**: Sensor validity, limit status and power mismatch are constantly detected inside the control thread, and protection is triggered in case of abnormality (e.g. shutdown or error reporting).

- **Position loop** PID (slow closed loop)
  - **Inputs**: target position (pos_setpoint) vs. actual position (encoder / PLL or sensorless estimation).
  - **Outputs**: generation of a correction value for the target velocity (vel_setpoint).
  The position loop is often purely proportional (P-control), and should cycle the cyclic setpoints. In some modes, anti-groove calibration data is also superimposed on the error correction.

  ```cpp
  // Note: the actual code distinguishes between linear and cyclic setpoints,
  // and introduces both drift prevention and gain scheduling (which reduces the feedback gain when the error is small).
  float pos_error = pos_setpoint - pos_estimate;
  if(config_.circular_setpoints) {
      pos_error = wrap_pm(pos_error, pos_wrap_value);
  }
  vel_setpoint = vel_setpoint_base + config_.pos_gain * pos_error;
  ```

- **Speed loop** PID (medium speed closed loop)
  - **Inputs**: desired speed generated by the position loop (with position P compensation), actual speed (from encoder / PLL output).
  - **Output**: calculation to obtain a torque expectation, which is converted to represent the current (iq_setpoint).
    The implementation uses a PI control structure, where the integral term is protected against saturation (e.g. limiting or attenuation). The sample code concept is shown below:

  ```cpp
  float vel_error = vel_desired - vel_estimate;
  vel_integrator_torque_ += (vel_integrator_gain * vel_error * dt);
  vel_integrator_torque_ = std::clamp(vel_integrator_torque_, -config_.  vel_integrator_limit, config_.vel_integrator_limit);
  // Here it is also possible to combine gain scheduling: lowering the P-action at small errors (gain_scheduling_multiplier)
  float torque = torque_setpoint + (vel_gain * gain_scheduling_multiplier * vel_error) + vel_integrator_torque_;
  ```

  Among them:
  - **Input modes**: different modes (e.g. VEL_RAMP, TRAP_TRAJ, MIRROR, TUNING, etc.) determine how the pos_setpoint/vel_setpoint/torque_setpoint is updated;
  - **Limiting mechanism**: ensures that the system output does not exceed the safe range by limiting the torque and vel_ setpoint to ensure that the system output does not exceed the safe range;
  - **Error detection**: triggers an error condition immediately when, for example, overspeed error or spinout (electromechanical power mismatch) is detected.

- **Current loop** PID (FOC control, high speed closed loop)
  - **Inputs**: target current (iq_setpoint and (optionally) id_setpoint) and measured current (Iq, Id sampled by ADC and transformed by Clarke / Park).
  - **Output**: Voltage command in d-q coordinate system calculated by PI control (including feed-forward term), then converted to PWM waveform by inverse Park transform and SVPWM algorithm. The sample code concept is as follows:

  ```cpp
  // Take the Iq component as an example (Id generally holds or tracks a predetermined value, depending on the algorithm and motor type)
  float Ierr_q = iq_setpoint - iq_measured;
  v_current_control_integral_q_ += Ierr_q * (i_gain * dt);

  // If overmodulation is detected (output vector amplitude exceeds limits), the integration term is attenuated (protection against integration storms)
  float mod_scalefactor = /* Scaling factor calculated from current output modulus */;
  if (mod_scalefactor < 1.0f) {
      // Lockout or decay points
      v_current_control_integral_q_ *= 0.99f;
  }
  vq = Vq_feedforward + (p_gain * Ierr_q + v_current_control_integral_q_);
  ```

  This is followed by an inverse Park transform and SVPWM algorithm similar to the one below:

  ```cpp
  // Convert mod_d, mod_q in d-q coordinates to α-β coordinates.
  float c_p = cos(pwm_phase);
  float s_p = sin(pwm_phase);
  float mod_alpha = c_p * mod_d - s_p * mod_q;
  float mod_beta = c_p * mod_q + s_p * mod_d;

  // SVM module maps (mod_alpha, mod_beta) to PWM timings (tA, tB, tC)
  auto [tA, tB, tC, success] = SVM(mod_alpha, mod_beta);
  ```

  - Note: The current control state is used for feedforward and load prediction in the actual control, taking into account R/L and feedforward compensation of the reverse electromotive force, which is reflected in the code in Motor::update() and FieldOrientedController::get_alpha_beta_output().

  > **Additional Notes**:
  > - All the PID parameters for each link (e.g. pos_gain, vel_gain, vel_integrator_gain, current loop p_gain, i_gain, etc.) are loaded from the NVM during system initialisation, and parameter tuning directly affects closed-loop dynamics and stability.
  > - In addition, the input modes (e.g. TRAP_TRAJ for trajectory planning mode) and anticogging measures are also preprocessed at the setpoint before the PID control chain, thus ensuring smooth and robust control instructions.

##### Driver Development
- **Encoder (ASA5147P)**: supports multiple types including: SPI, ABI, UVW, PWM; this motor driver supports two modes:
  - ABZ mode: uses the encoder mode of the stm32F4 timer peripheral, reads the position and speed feedback from the motor encoder
  - SPI mode: directly reads the ASA5147P's registers with higher 14-bit precision
- **FLASH (W25Q32JVSSIQ)**: for storing parameters, configurations, etc.;
- **Motor Driver (DRV8301)**
  - SPI Initialisation, Configuration Chip
  - Using stm32F4 advanced timer TIM1 TIM8: for 3-phase motor drive, reducing EMI; Complementary PWM output with dead time configuration (force PWM to be 50% during count down) to prevent short-circuiting of the upper and lower bridge arms straight through
- **Servo Driver (SG995)**: PWM mode of TIM2 to control the servo's angle.

##### Communication protocols
- **USB CDC/HID** **CAN bus**
  - fibre stack: a set of application layer protocols used for communication between the upper and lower units. The corresponding communication protocol stack is generated according to the contents of the ymal file.
  - Data type: format of packet Format of stream
- **UART Serial port**: to communicate with external sensors or Raspberry Pi.
  - Serial communication protocol: UART 921600 8N1, ASCII format; sends motor position and speed information continuously at 100Hz.

##### Configuration Tool UI
- **Parameter Configuration Tool**
  - QT-based visualisation interface;
  - Visual parameter tuning: motor pole-pair number, encoder CPR, brake resistance settings ......;
  - One-click calibration: measurement of the motor's electrical characteristics (i.e., motor phase resistance and phase inductance), as well as encoder offset calibration;
  - Real-time monitoring : Voltage, current, temperature feedback.
  - **Note**: The platform brushless motor used in this project is
- **PID Configuration Tool**: further unleash the performance of the FOC driver board. By adjusting the PID parameters, the controller can quickly respond to disturbances or changes in the system (e.g., applied external forces or changes in setpoints) without becoming unstable, which ensures that the motor driver board is able to control the motor in the most efficient way.
  - QT-based visualisation interface;
  - Real-time monitoring: position and speed feedback;
  - Sliders: visual adjustment of the PID parameters;
  - **Experience**: first set the Ki of the speed loop to 0 and the Kp of the position loop to a relatively small value. Gradually increase the Kp of the velocity loop by about 30% per iteration until the motor vibrates. In reality, as Kp increases, the current sound gets louder and louder and eventually vibrates at high frequency. Back off the Kp of the velocity loop to 50% of the vibration value and then set the integrator to 0.5 * bandwidth * vel_gain, where bandwidth is the total tracking bandwidth of the system. For this project, bandwidth was 10 hz. set the Ki of the velocity loop = 0.5 * 10 * vel_gain according to the formula. subsequently, gradually turn up the position loop Kp until some overshoot is seen. Back off the position loop Kp until there is no more overshoot. Debugging can be done by giving a Kp and then a position target to see the step response.
  - **Note**: Tests have found that the magnitude of the current sound has nothing to do with the Kp of the position loop, and everything to do with the Kp of the velocity loop; reduce the velocity loop Kp, and the current sound will be much smaller. It is reasonable to say that the larger the Kp of the position loop, the more overshoot, but actually found that the Kp is relatively small, the motor is very soft, at this time instead of overshoot. I feel that because the motor is too soft at this time, to the target position is a little out of control.

---

#### 🤖 ROS System Integration

##### 🧪 Simulation Platform Construction
The SLAM simulation platform is built first, which facilitates rapid algorithm verification and parameter debugging. The capacity of the physical battery is limited, and it is easy to damage to affect the project progress.

- **URDF**: robot model structural modeling;
  - **sw_urdf_exporter tool**: https://github.com/ros-industrial/sw_urdf_exporter
    - coordinate parameterization of solidworks modeling, use the tool sw_urdf_ exporter to convert the results to URDF format;
    - difficult to simulate a wheel-footed robot directly, here it is simply converted into a two-wheeled differential model for testing;
    - the tool will automatically calculate the mass and moment of inertia based on the model material and generate the corresponding STL file.
  - **Wheel_Robot**: base_link, laser_link, imu_link, left_wheel_link, right_wheel_link
    - base: fixed imu, laser_link, 8 arm (simplified model) : fix the arm directly on the base, can't move up and down
      - Mass: 0.459 kg, the main part of the robot.
      - Inertial origin: at (-0.00238, 0, 0.0969), probably due to design center of gravity shift.
      - Geometry and collisions: both defined using the base_link.STL file.
    - laser:
      - mass: 0.0866 kg, lightweight design.
      - Mounting position: fixed to base_link at (-0.0005, 0, 0.1246) by laser_joint.
      - Function: LIDAR sensor on top of the robot.
    - imu:
      - mass: 0.00216 kg, very light.
      - Mounting position: Fixed to base_link at (-0.01, 0, 0.0946) by imu_joint.
      - Function: Inertial measurement unit, near the center of the base, for attitude detection.
    - wheel:
      - Mass: about 0.01686 kg, symmetric design.
      - Geometry and collision: both use left_wheel_link.STL and right_wheel_link.STL.
      - Mounting position:
        - Left wheel: (0, 0.0655, 0.02596), rotating around y-axis (axis="0 1 0").
        - Right wheel: (0, -0.0655, 0.02596), rotating around the y-axis in the negative direction (axis=“0 -1 0”).
        - Wheel spacing: 0.174 m (symmetrically distributed on both sides of base_link).

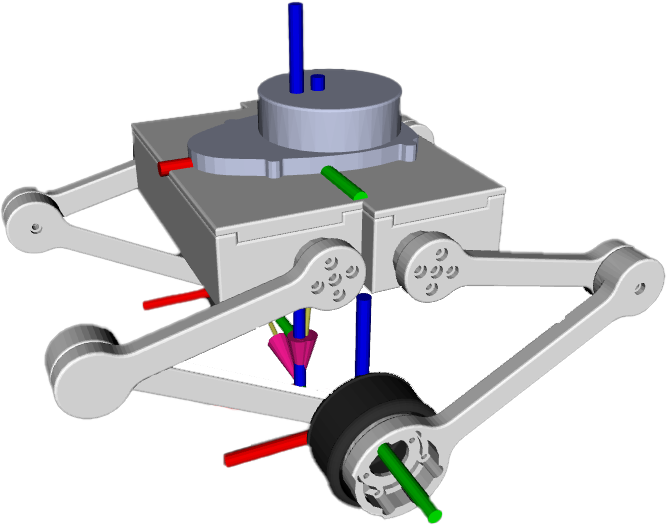
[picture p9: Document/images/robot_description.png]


- **Gazebo**: to realize the full simulation environment;
  - **gazebo plugin**: to add the plugin to the generated urdf plugin in order to generate the sensor data that the simulation environment allows to be needed;
  - **1. Differential Drive Plugin (`diff_drive`)**: to realize the differential drive control with the odometer release.
    - **Wheel_separation**: `0.174 m`
    - **Wheel_diameter**: `0.026 m`
    - **Maximum Torque & Acceleration**: `20 N-m` and `1.0 rad/s²` for small robots but need to be adjusted according to actual motor performance.
    - **TF Publishing**: `publish_odom_tf` is set to `true` to make sure the `odom` → `base_link` coordinate transformation is working.
  - **2. Joint state publishing plugin (`joint_state`)**: publish left and right wheel joint states to `/joint_states`.
    - **Update frequency**: `30 Hz`, consistent with the differential drive plugin, reasonable.
    - **Joint names**: correctly associate `left_wheel_joint` and `right_wheel_joint`, matches URDF.
    - **TF Publishing**: robot_state_publisher node runtime publishes coordinate transformations for `base_link` → `left_wheel_link` and `base_link` → `right_wheel_link`.
  - **3. IMU Sensor Plugin**: configures IMU sensors and publishes IMU data.
    - **Noise model**: add Gaussian noise for both angular velocity and linear acceleration to match the real IMU characteristics.
      - **Angular velocity noise**: standard deviation `2e-4 rad/s`, slight jitter, reasonable.
      - **Linear acceleration noise**: standard deviation `0.017 m/s²`, deviation mean `0.1 m/s²`, simulated zero-bias drift, consistent with low-cost IMU characteristics.
    - **Update frequency**: `100 Hz`, meets most SLAM algorithm requirements.
    - **TF Publishing**: robot_state_publisher node runtime publishes `base_link` → `imu_link` coordinate transformations.
  - **4. laser radar (LiDAR) plugin**: configure LiDAR and publish LiDAR data.
    - **Scanning parameters**: 360° scanning, `1°` resolution, `3.5 m` maximum range, `0.12 m` minimum, for indoor environments.
    - **Noise**: Gaussian noise (`stddev=0.01 m`), analog measurement error, reasonable.
    - **Publishing frequency**: `5 Hz`, low, may affect the real-time obstacle avoidance, it is recommended to upgrade to `10-20 Hz`.
    - **Installation position**: <pose>`0 0 0.075 0 0 0</pose> 0`, offset relative to `laser_link` needs to be superimposed with the actual height of the LIDAR in the URDF (`z=0.1246 m`) to ensure that the final position is correct.
    - **TF Publishing**: robot_state_publisher node runtime publishes the `base_link` → `laser_link` coordinate transformation.
  - **Simulation Scenarios**:
    - Scenario 1: [willowgarage](Software\ROS\wheel_robot_sim\src\wheel_robot\worlds\willowgarage.png)
      - Willow Garage The office environment is a classic simulation scenario used to testing robot navigation, SLAM and human-robot interaction algorithms.
    - Scenario 2: [cafe](Software\ROS\wheel_robot_sim\src\wheel_robot\worlds\cafe.png)
      - Cafe World is a simulation of a cafe scene designed to test robot navigation, SLAM and human-robot interaction algorithms in a dynamic environment.
    - Compare the two

        <div style="width: auto; display: table; margin: auto;">

        | **Features** | **Willow Garage** | **Cafe World** |
        |------------------------|---------- -------------------|-----------------------------|
        | **Scene Types** | Office Environment | Service Scene (Cafe) |
        | **Dynamic Elements** | Static Obstacle Oriented | Dynamic Pedestrians + Movable Objects |
        | **Testing Focus** | Navigation, SLAM | Human-Computer Interaction, Obstacle Avoidance | | **Complexity** | Medium (structured layout) | High (lots of dynamic interference) |

        </div>

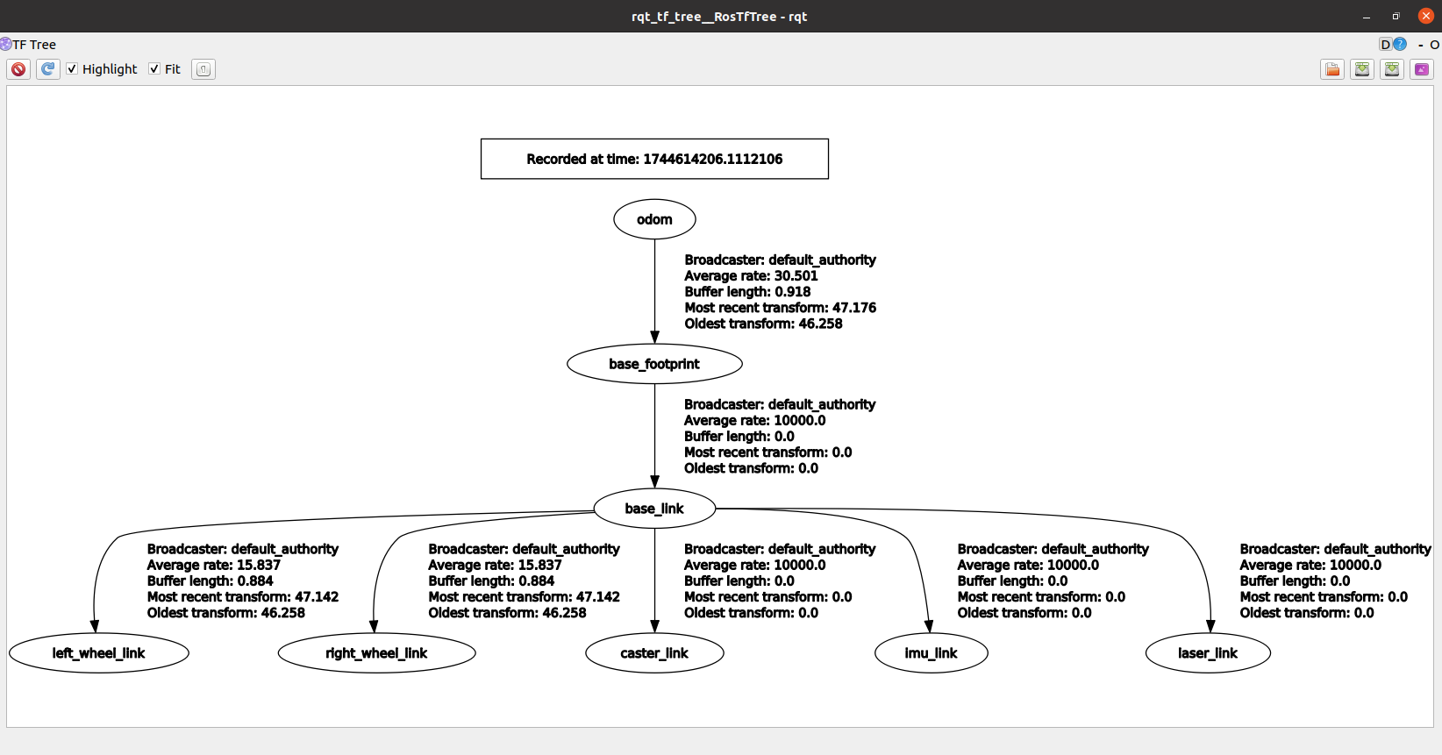
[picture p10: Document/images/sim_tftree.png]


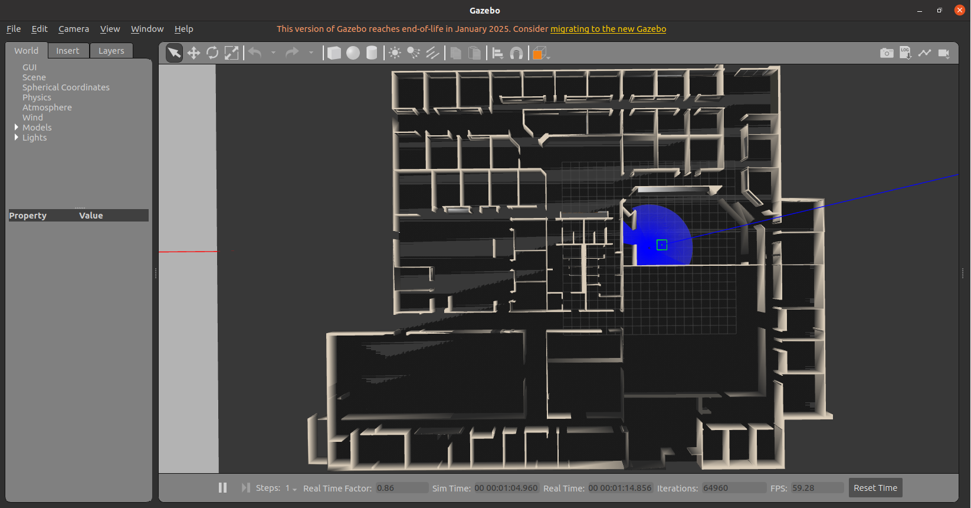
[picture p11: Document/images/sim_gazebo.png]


- **Cartographer + Navigation2**: Realize map building and navigation path planning.
  - Map building: **Cartographer**;
    - Introduction: Cartographer is an open source real-time SLAM (Simultaneous Localization and Map Building) system developed by Google, which supports map building in both 2D and 3D environments. It realizes high-precision and low-drift real-time map building by fusing multi-sensor data (e.g. LIDAR, IMU, odometer, etc.), which is widely used in robotics, autonomous driving and other fields.
    - Principle:
      1. **Front-end Scanning Matching**: Using local submaps (Submaps) construction, the robot position is estimated by matching real-time LiDAR data with submaps.
      2. **Backend Optimization**: eliminates cumulative errors using Loop Closure and Global Optimization (SLAM framework based on graph optimization).
      3. **Multi-sensor fusion**: combines data from IMU, odometer, etc. to improve the robustness of position estimation.
    - Advantages:
      - **Efficient real-time**: supports real-time graph building, suitable for dynamic environment applications.
      - **Multi-sensor support**: Flexible fusion of LIDAR, IMU and other data to adapt to complex scenes.
      - **Strong closed-loop detection**: Significantly reduces cumulative errors in long-term operation and improves the global consistency of the map.
      - **Open source and scalable**: clear code structure, support 2D/3D map building, active community.
    - Disadvantages:
      - **Complicated configuration**: parameter tuning relies on experience and needs to be optimized for different sensors and environments.
      - **High computational resource requirements**: high hardware requirements for 3D mapping or large-scale scenes.
      - **Limited dynamic environment processing**: mainly designed for static environments, dynamic obstacles may affect the accuracy of map building.
    - [Configuration](Software\ROS\wheel_robot\src\carto\config\carto.lua):

  - Navigation Path Planning: **Navigation2**;
    - Introduction: Navigation2 is the official navigation framework in ROS 2, used for path planning and autonomous navigation of mobile robots. It supports global path planning, local obstacle avoidance, recovery behavior, etc. It is suitable for wheeled robots, service robots and other scenarios.
    - Principle:
      1. **Global Planning**: Generate the global optimal path based on Costmap and algorithms (e.g., A*, Dijkstra).
      2. **Local Planning**: Combine with Dynamic Window Approach (DWA) or Timed Elastic Band (TEB) algorithm to avoid obstacles and track the path in real time. 3.
      3. **Behavior Tree Control**: manages navigation states (e.g., replanning, recovery mode) through a Behavior Tree (BT).
    - Advantages:
      - **Modular design**: plug-in architecture supports customization of algorithms (e.g., changing planners or controllers).
      - **Dynamic environment adaptation**: real-time updating of the cost map to effectively deal with dynamic obstacles.
      - **Cross-platform compatibility**: Based on ROS 2, supports multiple robot hardware and simulation environments.
      - **Behavior Tree Management**: Flexible handling of complex navigation logic (e.g. fault recovery, multi-target switching).
    - Disadvantages:
      - **Real-time limitations**: localized planning may be delayed in dense obstacles or complex terrain.
      - **Dependence on sensor quality**: localization (e.g. AMCL) and obstacle avoidance effects are highly affected by sensor accuracy.
      - **Complicated configuration**: fine tuning of parameters (e.g., velocity, acceleration) for robot dynamics is required.
    - [Configuration](Software\ROS\wheel_robot\src\nav2\param\fishbot_nav2.yaml):

##### 🚗 Physical Deployment and Control
After completing the SLAM simulation experiments, the chimera on the software has basically been completed, and the next step is to just replace the sensor data used in the simulation with the gazebo-generated sensor data used in the simulation to be replaced with the sensor data used in the physical object, and debug the control algorithm accordingly; then the control of the algorithm on the robot is transferred to the two wheels and servos through the communication protocol between the Raspberry Pi and the FOC driver. In addition, because a simple two-wheeled differential cart model is used in the simulation, the wheeled robot built in the real world needs to be debugged with more complex control algorithms.

- **Sensor Access and Driver**
  - **AS5147P**: 14-bit rotary encoder for motor position feedback;
    - Raspbery Pi's UART communication with the motor driver board occupies the Rapsberry's serial port terminal, which will cause the Raspberry to be unable to enter the system;
      - Disable UART0 as the system console and disable Bluetooth
      - Cancel the Raspberry u-boot boot wait time
    - Receive data from the motor driver board UART communication thread and decode it;
  - **CMP10A IMU**: 3-axis gyroscope + accelerometer + magnetometer + barometer;
    - Configure and calibrate the IMU module through the manufacturer's provided host software and increase the sampling rate to 200Hz;
    - Connect the IMU module to the Raspberry Pi. Bind the IMU module to the USB port connected to the Raspberry Pi for subsequent direct data reading;
    - Write the IMU driver;
  - **YDLIDAR X3**: LIDAR, 360° scanning, 0.12-8m range;
    - Configure and calibrate the IMU module via the vendor-supplied host computer software and increase the sampling rate to 100Hz; - Configure and calibrate the IMU module via the vendor-supplied host computer software and increase the sampling rate to 100Hz. sampling rate to 100Hz;
    - Install YDLIDAR SDK on Raspberry Pi;
    - Bind the YDLIDAR module to the USB port connected to the Raspberry Pi, so as to facilitate the subsequent direct reading of the data;
    - Write the IMU driver;
- **Data Processing**
  - **Dodom Odometer**
    - Decode the encoder data coming from the motor driver board to get the motor position, position, and distance. Decode the encoder data from the motor driver board to get the motor position and velocity information;
    - Perform kinematic orthogonal solving of the position information of the two wheels of the wheel-footed robot to get the position information under the robot coordinate system;
    - Output the ROS Odometry message for other nodes;
  - **IMU Attitude Estimation**
    - Decode the data coming from the IMU module to get the attitude information;
    - Output the ROS IMU message for other nodes;
  - **YDlidar Point Cloud Processing**
    - Receive data from YDLIDAR module and decode;
    - Output ROS laserscan message for other nodes;
- **Motion Control**
  - Robot Self-Balancing:
    - Balance Control Algorithm: Serial PID Control (Velocity Loop + Position Loop Height Loop);
    ...
  - Robot Motion:
    - listens to cmd_vel and modifies target_linear_vel and target_angular_vel for motion control;

- **SLAM deployment**
  ```mermaid
  graph TD

    %% Node Definitions
    subgraph S1[🟦 Underlying Data]
      Sensors[Sensors node<br/>IMU, Laser, Odometry]:::sensor
      WheelRobot[Wheel Robot node<br/>Publishing Robot Descriptions with tf]:::sensor
    end

    subgraph S2[🟩 function module]
      MotionCtrl[MotionControl node<br/>subscribes to IMU/listsens to cmd_vel]:::module
      Cartographer[Cartographer node<br/>map building & map publishing]:::module
    end

    subgraph S3[🟨 External Interactive Interface]
      WebService[Web Service<br/>Send cmd_vel/Subscribe to map]:::external
    end

    %% Data Flow Connections
    Sensors -- IMU/Laser/Odom data --> Cartographer
    Sensors -- IMU data --> MotionCtrl
    WheelRobot -- Robot Description/TF --> Cartographer

    WebService -- cmd_vel Control commands --> MotionCtrl
    MotionCtrl -- Motion control feedback --> Cartographer
    Cartographer -- map map --> WebService

    %% Style settings
    classDef sensor fill:#cce5ff,stroke:#3399ff,stroke-width:2px;
    classDef module fill:#d4edda,stroke:#28a745,stroke-width:2px;
    classDef external fill:#fff3cd,stroke:#ffc107,stroke-width:2px;
  ```

  - Map build: cartographer;
    - start IMU, Laser, Odometry node: start data receiving and publishing;
    - start motion control node: subscribe IMU data to keep balance, listen to cmd_vel for motion control;
    - start wheel robot node: publish robot description and tf transform for each link;
    - Start cartographer node: subscribe LIDAR, IMU, Odometry data, start map building to publish map data;
    - Start web service: publish cmd_vel motion control commands, subscribe map to update map display;
  - Map display
    - Raspbery Pi Remote Desktop for program debugging and map display
    - Web console: Map display, path planning, control command display;

##### 🌐 Web Console
- Map Browsing: real-time map update, route display;
- Control Functions: directional buttons, virtual joystick control;

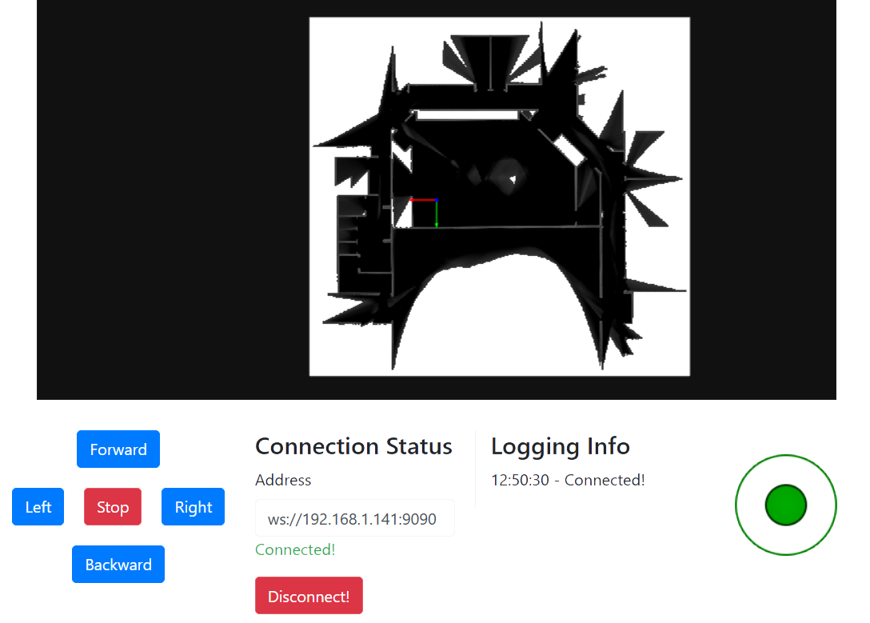
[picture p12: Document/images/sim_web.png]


### Follow-up work 

1. Separate the balance control from the ROS, and directly integrate the balance control into the motor driver board to reduce the dependence on the Raspberry Pi; 
2. Introduce a thermal management monitoring system to ensure the long-term stability of the operation: add fan cooling, etc. 
3. Power management system, add a soft-start control, attenuate the surge phenomenon on the device during the power on the pressure and impact; separate power supply to the Raspberry and to the servo to reduce the impact on the Raspberry during operation; 4. Raspberry and the servo power supply separation, reduce the servo operation on the impact of the Raspberry; 
4. shell structure optimization, especially the Arm part, weaken the friction of the joints, to get a smoother movement

<p align="right">(<a href="#top">top</a>)</p>

<!-- CONTRIBUTING -->
## Contributing

Contributions are what make the open source community such an amazing place to learn, inspire, and create. Any contributions you make are **greatly appreciated**.

If you have a suggestion that would make this better, please fork the repo and create a pull request. You can also simply open an issue with the tag "enhancement".
Don't forget to give the project a star! Thanks again!

1. Fork the Project
2. Create your Feature Branch (`git checkout -b feature/AmazingFeature`)
3. Commit your Changes (`git commit -m 'Add some AmazingFeature'`)
4. Push to the Branch (`git push origin feature/AmazingFeature`)
5. Open a Pull Request
<p align="right">(<a href="#top">top</a>)</p>

<!-- LICENSE -->
## License

Distributed under the MIT License. See `LICENSE` for more information.
<p align="right">(<a href="#top">top</a>)</p>

<!-- CONTACT -->
## Contact

MoonGrt - 1561145394@qq.com
Project Link: [MoonGrt/Wheel_Robot](https://github.com/MoonGrt/Wheel_Robot)

<p align="right">(<a href="#top">top</a>)</p>

<!-- ACKNOWLEDGMENTS -->
## Acknowledgments

Use this space to list resources you find helpful and would like to give credit to. I've included a few of my favorites to kick things off!

* [Choose an Open Source License](https://choosealicense.com)
* [GitHub Emoji Cheat Sheet](https://www.webpagefx.com/tools/emoji-cheat-sheet)
* [Malven's Flexbox Cheatsheet](https://flexbox.malven.co/)
* [Malven's Grid Cheatsheet](https://grid.malven.co/)
* [Img Shields](https://shields.io)
* [GitHub Pages](https://pages.github.com)
* [Font Awesome](https://fontawesome.com)
* [React Icons](https://react-icons.github.io/react-icons/search)
<p align="right">(<a href="#top">top</a>)</p>

<!-- MARKDOWN LINKS & IMAGES -->
<!-- https://www.markdownguide.org/basic-syntax/#reference-style-links -->
[contributors-shield]: https://img.shields.io/github/contributors/MoonGrt/Wheel_Robot.svg?style=for-the-badge
[contributors-url]: https://github.com/MoonGrt/Wheel_Robot/graphs/contributors
[forks-shield]: https://img.shields.io/github/forks/MoonGrt/Wheel_Robot.svg?style=for-the-badge
[forks-url]: https://github.com/MoonGrt/Wheel_Robot/network/members
[stars-shield]: https://img.shields.io/github/stars/MoonGrt/Wheel_Robot.svg?style=for-the-badge
[stars-url]: https://github.com/MoonGrt/Wheel_Robot/stargazers
[issues-shield]: https://img.shields.io/github/issues/MoonGrt/Wheel_Robot.svg?style=for-the-badge
[issues-url]: https://github.com/MoonGrt/Wheel_Robot/issues
[license-shield]: https://img.shields.io/github/license/MoonGrt/Wheel_Robot.svg?style=for-the-badge
[license-url]: https://github.com/MoonGrt/Wheel_Robot/blob/master/LICENSE

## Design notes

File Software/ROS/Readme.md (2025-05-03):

## Raspberry Pi 4 ROS2 Set

### 寻找IP地址
- 屏幕终端查询
- Advanced_IP_Scanner
- cmd 输入 ```ping raspberrypi.local``` ("raspberrypi"是树莓派的主机名)

### 安装 ubuntu 20.04

### WIFI 配置
- Step1: 编辑文件: `sudo nano /etc/netplan/50-cloud-init.yaml`
    > 注意格式，不要有多余的空格(2个空格的缩进)
    ```
    network:
      version: 2
      wifis:
        wlan0:
          dhcp4: true
          optional: true
          access-points:
            "Moon":
              password: "asdfghjkl"
            "TP-LINK_90D4":
              password: "15908133965"
    ```

- Step2: 修改内容:
    ```
    sudo netplan -debug try
    sudo netplan -debug generate
    sudo netplan -debug apply
    ```

### 安装 ROS2 Foxy
`wget http://fishros.com/install -O fishros && bash fishros`

### 安装 tf_transformations
```bash
sudo pip3 install transforms3d
sudo apt-get install ros-foxy-tf-transformations
```

### 安装 Cartographer Nav2
```bash
sudo apt install ros-foxy-cartographer
sudo apt install ros-foxy-cartographer-ros

sudo apt install ros-foxy-nav2-*
```

### 安装 python 库
- 模糊PID控制库: `pip install scipy scikit-fuzzy networkx`

### 安装 rosbridge_server
`sudo apt install ros-$ROS_DISTRO-rosbridge-suite`

### 安装 Odrive
- `pip install odrive`
- 添加环境: 
    ```
    echo 'export PATH=$HOME/.local/bin:$PATH' >> ~/.bashrc
    source ~/.bashrc
    ```
- 设备权限: 
    ```bash
    sudo bash -c "curl https://cdn.odriverobotics.com/files/odrive-udev-rules.rules > /etc/udev/rules.d/91-odrive.rules && udevadm control --reload-rules && udevadm trigger"
    ```

### Issues
#### 1. Odrive 和 Raspberry 连接，导致 Raspberry 无法进入系统
- Step1. 禁用 UART 作为系统控制台
  - 编辑 cmdline.txt: `sudo nano /boot/firmware/cmdline.txt`
  - 移除 console=serial0,115200
- Step2. 取消 u-boot 开机等待时间
  - 串口输入任意内容，进入 u-boot
  - 输入: `setenv bootdelay -2`
  - 保存: `saveenv`
- Step3. 重新启动 Raspberry Pi

#### 2. Odrive GPIO8 无法输出PWM信号
> 原因: Odrive GPIO8 与 Raspberry-Pi SPI CE0 共享，被拉低电平
- Step1: 关闭 Raspberry-Pi 的 SPI 功能
  - 编辑 config.txt: `sudo nano /boot/firmware/config.txt`
  - 取消 SPI 功能: `dtparam=spi=off`
- Step2: (上述方法无用) 强制禁用 SPI
  - 编辑 usercfg.txt: `sudo nano /boot/firmware/usercfg.txt`
  - 添加 `dtparam=spi=off`
- Step3. 重新启动 Raspberry Pi

#### 3. 树莓派串口无法使用
> 原因: 树莓派的串口默认连接到 ttyAMA0，而 ttyAMA0 被 终端和蓝牙
- Step1: 关闭终端和蓝牙
  - 关闭终端: 查看issue1
  - 关闭蓝牙: 
    - 编辑 config.txt: `sudo nano /boot/firmware/config.txt`
    - 添加: `dtoverlay=disable-bt`
  - bash运行: `sudo systemctl disable bluetooth`
    <!-- - 进入root用户，bash运行: `sudo su` -->

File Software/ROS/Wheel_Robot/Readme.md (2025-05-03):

## Wheel Robot

### wheel_robot
#### 运行 wheel_robot 节点
> 该 launch 文件同时运行robot, imu, ydlidar, motor, web节点
```
source install/setup.bash
ros2 launch wheel_robot robot.launch.py
```

### carto
#### 运行 carto 节点
```
source install/setup.bash
ros2 launch carto cartographer.launch.py
```

### imu
#### 绑定 imu USB设备
> 连接上 imu 后，运行以下命令绑定 imu USB设备。
```
sudo chmod 777 src/imu/bind_usb.sh
sudo sh src/imu/bind_usb.sh
```
> 输入以下指令, 强制 udev 重新加载, 并测绑定端口是否成功:
```
sudo udevadm control --reload-rules
sudo udevadm trigger
ll /dev/imu
```
#### 运行 imu 节点
```
source install/setup.bash
ros2 launch imu imu.launch.py
```

### ydlidar
#### 安装 YDLidar-SDK
解压YDLidar-SDK-master.tar.xz, 在解压后的文件夹中, 执行:
```
mkdir build
cd build
cmake ..
make -j4
sudo make install
```
> 然后就可以删除该文件夹

#### 绑定 ydlidar USB设备
> 注意: imu 和 ydlidar 的USB-ID完全相同，因此使用CP210xSetIDs.exe工具将 ydlidar 的 serial 项 从默认的"0001"改为"0002"

> 连接上 ydlidar 后，运行以下命令绑定 ydlidar USB设备。
```
sudo chmod 777 src/ydlidar/bind_usb.sh
sudo sh src/ydlidar/bind_usb.sh
```
> 输入以下指令, 强制 udev 重新加载, 并测绑定端口是否成功:
```
sudo udevadm control --reload-rules
sudo udevadm trigger
ll /dev/ydlidar
```
#### 运行 ydlidar 节点
```
source install/setup.bash
ros2 launch ydlidar ydlidar.launch.py
```

### motor
#### 绑定 motor USB设备
> 如果是用虚拟机usb连接Odribe则可以绑定usb; Raspberry Pi 用引脚UART连接则不需要
> 连接上 motor 后，运行以下命令绑定 motor USB设备。
```
sudo chmod 777 src/motor/bind_usb.sh
sudo sh src/motor/bind_usb.sh
```
> 输入以下指令, 强制 udev 重新加载, 并测绑定端口是否成功:
```
sudo udevadm control --reload-rules
sudo udevadm trigger
ll /dev/motor
```
#### 运行 motor 节点
```
source install/setup.bash
ros2 run motor motor
```

### Issue

#### colcon build 卡死

1. **内存不足**

树莓派（特别是 2GB 或 4GB RAM 版本）在编译大型 ROS2 包时可能会内存溢出。

**解决办法：**

* **安装 dphys-swapfile 工具**
  ```bash
  sudo apt-get update
  sudo apt-get install dphys-swapfile
  ```

* **启用交换分区（Swap）**
  ```bash
  sudo dphys-swapfile swapoff
  sudo nano /etc/dphys-swapfile
  ```
  修改：
  ```ini
  CONF_SWAPSIZE=2048  # 或更大，比如 4096
  ```
  然后：
  ```bash
  sudo dphys-swapfile setup
  sudo dphys-swapfile swapon
  ```

2. **并行编译线程太多**

默认 `colcon build` 会使用多线程，但树莓派资源有限，容易卡死。

**解决办法：**

* 限制并行编译线程数，例如用 2 个线程：
  ```bash
  colcon build --executor sequential --parallel-workers 2
  ```

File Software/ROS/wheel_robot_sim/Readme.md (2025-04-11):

### Wheel Robot Simulation

#### 运行 wheel_robot 节点
> 首次运行, gazebo 可能需要下载一些文件, 请耐心等待.
```
source install/setup.bash
ros2 launch wheel_robot gazebo.launch.py
```

#### 运行 wheel_robot_cartographer 节点
```
source install/setup.bash
ros2 launch wheel_robot_cartographer cartographer.launch.py
```

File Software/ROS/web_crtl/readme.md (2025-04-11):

### 使用步骤

#### ROS部分
- Step1. 启动机器人
  - 启动机器人仿真和建图程序
    ```bash
    source install/setup.bash
    ros2 launch fishbot_description gazebo.launch.py
    ```
    ```bash
    source install/setup.bash
    ros2 launch fishbot_cartographer cartographer.launch.py
    ```
- Step2. 启动rosbridge websocket
  - `ros2 run rosbridge_server rosbridge_websocket`

#### 网页部分
- Step1. 查ROS主机IP地址
  - 获取主机IP地址
- Step2. 启动ROSbridge
  - 打开index.html以及main.js文件，并修改url，改成ROS主机IP地址
- Step3. 启动网页
  - 使用浏览器打开index.html文件: 在文件夹中，双击文件，便可自动在浏览器打开
- Step4. 连接ROS节点
  - 点击Connect按钮，连接rosbridge_server

### Issues
#### 1. 'OccupancyGrid' object has no attribute '_slot_types'
```
Traceback (most recent call last):
  File "/opt/ros/foxy/lib/python3.8/site-packages/rosbridge_library/internal/subscription_modifiers.py", line 161, in run
    MessageHandler.handle_message(self, msg)
  File "/opt/ros/foxy/lib/python3.8/site-packages/rosbridge_library/internal/subscription_modifiers.py", line 73, in handle_message
    self.publish(msg)
  File "/opt/ros/foxy/lib/python3.8/site-packages/rosbridge_library/capabilities/subscribe.py", line 159, in _publish
    self.publish(message, self.fragment_size, self.compression)
  File "/opt/ros/foxy/lib/python3.8/site-packages/rosbridge_library/capabilities/subscribe.py", line 318, in publish
    outgoing_msg = message.get_cbor(outgoing_msg)
  File "/opt/ros/foxy/lib/python3.8/site-packages/rosbridge_library/internal/outgoing_message.py", line 38, in get_cbor
    outgoing_msg["msg"] = self.get_cbor_values()
  File "/opt/ros/foxy/lib/python3.8/site-packages/rosbridge_library/internal/outgoing_message.py", line 33, in get_cbor_values
    self._cbor_values = extract_cbor_values(self._message)
  File "/opt/ros/foxy/lib/python3.8/site-packages/rosbridge_library/internal/cbor_conversion.py", line 53, in extract_cbor_values
    for slot, slot_type in zip(msg.__slots__, msg._slot_types):
AttributeError: 'OccupancyGrid' object has no attribute '_slot_types'
```

**Solution**
这个问题是由于ROS2（Foxy）的消息结构与ROS1不同，导致rosbridge_library在处理OccupancyGrid消息时无法找到预期的_slot_types属性。以下是解决方案：

修改以下cbor_conversion.py文件中的extract_cbor_values函数:
```python
def extract_cbor_values(msg):
    """Extract a dictionary of CBOR-friendly values from a ROS message.

    Primitive values will be casted to specific Python primitives.

    Typed arrays will be tagged and packed into byte arrays.
    """
    out = {}
    for slot, slot_type in msg.get_fields_and_field_types().items():
        val = getattr(msg, slot)

        # string
        if slot_type in STRING_TYPES:
            out[slot] = str(val)

        # bool
        elif slot_type in BOOL_TYPES:
            out[slot] = bool(val)

        # integers
        elif slot_type in INT_TYPES:
            out[slot] = int(val)

        # floats
        elif slot_type in FLOAT_TYPES:
            out[slot] = float(val)

        # time/duration
        elif slot_type in TIME_TYPES:
            out[slot] = {
                "sec": int(val.sec),
                "nanosec": int(val.nanosec),
            }

        # byte array
        elif slot_type in BYTESTREAM_TYPES:
            out[slot] = bytes(val)

        # bool array
        elif slot_type in BOOL_ARRAY_TYPES:
            out[slot] = [bool(i) for i in val]

        elif slot_type in STRING_ARRAY_TYPES:
            out[slot] = [str(i) for i in val]

        # numeric arrays
        elif slot_type in TAGGED_ARRAY_FORMATS:
            tag, fmt = TAGGED_ARRAY_FORMATS[slot_type]
            fmt_to_length = fmt.format(len(val))
            packed = struct.pack(fmt_to_length, *val)
            out[slot] = Tag(tag=tag, value=packed)

        # array of messages
        elif type(val) in LIST_TYPES:
            out[slot] = [extract_cbor_values(i) for i in val]

        # message
        else:
            out[slot] = extract_cbor_values(val)

    return out
```

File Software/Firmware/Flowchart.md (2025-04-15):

```mermaid
graph TD
    A[系统启动] --> B[NVM中加载配置参数]
    B --> C[系统初始化]
    C --> C1[初始化外设<br>GPIO/PWM/USB/SPI/DMA...]
    C --> C2[中断配置<br>优先级设置/注册处理函数/启动中断]
    C --> C3[RTOS初始化<br>内存/调度器/时钟...]

    C3 --> D[创建主线程]
    D --> E[启动调度器]
    E -.-> F[主线程执行]
    F --> F1[启动外设<br>PWM/ADC/TIM]
    F1 --> F2[创建辅助线程]
    F2 --> F2a[通信处理线程]
    F2 --> F2b[系统监控线程<br>模拟采集/状态监控]
    F2 --> F2c[电机状态管理线程]
    F2 --> G[退出并删除主线程]

    G --> H[进入实时运行状态]

    %% 实时线程部分
    subgraph 实时运行状态
        H1[通信线程]
        H1 --> H1a[定期上报状态]
        H1 --> H1b[USB/CAN中断接收指令]
        H1 --> H1c[UART轮询接收指令]
        H1b --> H1d[接收及解析外部控制指令]
        H1c --> H1d
        H1d --> H1e[更新控制目标]
        H1c --> H1f[UART轮询发送数据<br>电机速度/位置]

        H2[监控线程]
        H2 --> H2a[采集系统状态<br>温度/电压/错误信号]
        H2a --> H2b[异常检测]

        H3[电机状态线程]
        H3 --> H3a[周期刷新<br>每个轴的状态信息]
        H3a --> H3b[同步当前控制状态<br>工作模式/反馈变量]
        H3b --> H3c[转发错误信息]
    end

    %% 控制链（由硬件定时器及中断驱动）
    subgraph 控制链执行-核心定时器中断
        T1[高精度定时器中断<br>控制周期触发] --> T2[更新系统时隙]
        T2 --> T3[软件触发控制中断<br>调度控制计算流程]
        T3 --> T4[触发采样及数据获取<br>电流/编码器/传感器数据]
        T4 --> T5[执行实时控制算法回路<br>（位置/速度/电流）]
        T5 --> T6[重置状态 & 检查安全条件]
        T6 --> T7[执行闭环控制更新<br>状态估计/PID调节/PWM更新]
        T7 --> T8[验证周期完整性/安全检查]
        T5 -->|异常检测| D1[中断触发保护<br>停机/错误上报]
        T8 -->|异常检测| D1
    end

    %% 辅助中断
    subgraph 辅助中断
        U1[USB/CAN 通信中断]
        U1 --> U2[接收指令数据]
        U2 --> U3[写入数据队列]

        G1[GPIO EXIT中断]
        G1 --> G2[检测故障信号]
        G2 --> G3[DRV8301 故障中断...<br>nFAULT 拉低...] --> G3a[断电/上报错误]
        G2 --> G4[编码器 Z 相位中断<br>] --> G4a[编码器校准] --> T4

        E1[辅助TIM中断]
        E1 --> E2[编码器中断] --> E2a[记录编码器边沿] --> T4
        E1 --> E3[PWM 捕获中断] --> E3a[读取PWM信号宽度] --> T4
    end

    %% 交互链接
    H1e --> T5
    H2b -->|异常反馈| D1
    H3c -->|错误反馈| D1
    G3a -->|DRV8301故障| D1
    U3 -->|指令队列| H1b

    %% 样式定义
    classDef init fill:#CDEDF6,stroke:#2B7A78,color:#17252A;
    classDef thread fill:#E6F7D9,stroke:#4CAF50,color:#1B5E20;
    classDef runtime fill:#FFF3CD,stroke:#FFC107,color:#7F4E00;
    classDef control fill:#E1D5E7,stroke:#9C27B0,color:#4A148C;
    classDef interrupt fill:#FFE5B4,stroke:#FF9800,color:#E65100;
    classDef error fill:#FADBD8,stroke:#C0392B,color:#641E16;

    %% 分类标注
    class A,B,C,C1,C2,C3,D,E init
    class F,F1,F2,F2a,F2b,F2c,G,H,H1,H2,H3,H1a,H1b,H1c,H1d,H1e,H1f,H2a,H2b,H3a,H3b,H3c thread
    class T1,T2,T3,T4,T5,T6,T7,T8 control
    class U1,U2,U3,G1,G2,G3,G3a,G4,G4a,E1,E2,E2a,E3,E3a interrupt
    class D1 error
```

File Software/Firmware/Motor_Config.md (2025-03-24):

## Motor Configuration
[电机配置实例](https://blog.csdn.net/abf1234444/article/details/104967023)

> 进行配置前建议首先执行一遍擦除配置:
> dev0.erase_configuration()
> dev0.reboot()

### Odrive 参数
| 参数 | Odrive |
|---|---|
| 版本 | ODrive 3.6-24V  |

### 锂电池参数
| 参数 | 锂电池 |
|---|---|
| 电池容量 | 3.0Ah |
| 输出电流 | 5 A |
| 输出电压 | 24 V |

### 编码器参数
| 参数 | AS5147P |
|---|---|
| CPR | 4096 |
| PPR | 1024 |

### PM3510 参数
| 参数 | PM3510 |
|---|---|
| 额定电压 (Nominal voltage)  | 12 V |
| 额定电流 (Nominal current)  | 0.53 A |
| 额定扭矩 (Nominal torque) | 0.11 N.M |
| 额定转速 (Nominal Speed) | 945 rpm |
| 最大转速 (Max Speed) | 1250 rpm |
| 堵转扭矩 (Stall torque) | 0.16 N.M |
| 堵转电流 (Stall current) | 0.80 A |
| 相间电阻 (Phase to phase resistance) | 7.8 |
| 相间电感 (Phase to phase inductance) | 3.95 Mh |
| 转速常数 (Speed constant) | 45 rpm/V |
| 扭矩常数 (Torque constant)  | 0.20 N.M/A |
| 转子惯量 (Rotor inertia) | 81 gm² |
| 极对数 (Number of poles) | 11 |
| 电机重量 (Motor weight) | 73 g |
| 工作温度范围 (Working temperature) | -20 / 80 ℃ |
| 最高退磁温度 (Max demagnetize temperature) | 120 ℃ |
| 定子尺寸 (Stator dimension (D×L)) | 35×10 |
| 绕线圈数 (Turns) | 36 |
| 滑环尺寸 (Slipring) | 12.5 mm |

### 1. 配置参数
#### 1.1 基本配置
- `dev0.config.brake_resistance = 0`
  - PM3510 电机的功率较小, 且使用锂电池供电, 不需要外部刹车电阻。
- `dev0.config.dc_bus_undervoltage_trip_level = 20`
  - 锂电池输出电压为 24V, 考虑放电特性, 设置欠压保护在 20V 可避免过放。
- `dev0.config.dc_bus_overvoltage_trip_level = 30`
  - 保护 ODrive 电路, 避免电压瞬间超过 ODrive 的额定电压范围24V。
- `dev0.config.dc_max_positive_current = 40`
  - 限制最大正向电流为锂电池输出电流 40A, 避免过流损坏电池和 ODrive。
- `dev0.config.dc_max_negative_current = -1`
  - 允许轻微的再生电流回灌, 避免过度充电电池。
- `dev0.config.max_regen_current = 1`
  - 限制再生电流, 保护电池不被回灌过多电流。开关电源进行供电所以不具备电能回收功能。(小于 4A)
#### 1.2 电机配置
- `dev0.axis0.motor.config.pole_pairs = 11`
  - PM3510 电机的极对数为 11。
- `dev0.axis0.motor.config.calibration_current = 2`
  - 设置校准电流为 2A, 避免过热或损坏电机。
- `dev0.axis0.motor.config.resistance_calib_max_voltage = 10`
  - 电机的相间电阻较高(7.8Ω)，调整calibration_current和resistance_calib_max_voltage。
- `dev0.axis0.motor.config.motor_type = MOTOR_TYPE_HIGH_CURRENT`
  - PM3510 是无刷云台直流电机, 适合使用该模式。云台电机：MOTOR_TYPE_GIMBAL；大电流电机：MOTOR_TYPE_HIGH_CURRENT。
- `dev0.axis0.motor.config.current_lim = 2`
  - 限制最大电流在 2A, 匹配电机堵转电流, 避免电机过载。
- `dev0.axis0.motor.config.requested_current_range = 40`
  - 设定电流范围为 40A, 满足电机需求并保持电流采样稳定。
- `dev0.axis0.motor.config.torque_constant = 0.20`
  - 设置扭矩常数为 0.20 N.M/A, 匹配 PM3510 电机特性。
#### 1.3 编码器配置
- `dev0.axis0.encoder.config.mode = ENCODER_MODE_INCREMENTAL`
  - AS5147P 为增量式编码器, 使用增量模式。
- `dev0.axis0.encoder.config.use_index = True`
  - 使用索引信号进行初始化。
- `dev0.axis0.encoder.config.cpr = 4096`
  - AS5147P 编码器 CPR 为 4096。
- `dev0.axis0.encoder.config.bandwidth = 2000`
  - 设置编码器带宽为 2000Hz, 可滤除噪声且保持响应速度。
- `dev0.axis0.config.calibration_lockin.current = 1`
  - 使用 1A 校准电流, 避免电机过热。
- `dev0.axis0.config.calibration_lockin.ramp_time = 0.5`
  - 0.5 秒的斜坡时间让电流缓慢上升, 减少电机冲击。
- `dev0.axis0.config.calibration_lockin.ramp_distance = 3.14159`
  - 让电机旋转半圈（π弧度）确保充分校准。
- `dev0.axis0.config.calibration_lockin.accel = 10`
  - 设定加速度, 确保电机稳定旋转。
- `dev0.axis0.config.calibration_lockin.vel = 20`
  - 校准时设定速度为 20 rad/s。
#### 1.4 控制器配置
- `dev0.axis0.controller.config.control_mode = CONTROL_MODE_VELOCITY_CONTROL`
  - 选择速度控制模式。
- `dev0.axis0.controller.config.vel_limit = 100`
  - 将最大转速 1250 rpm 转换为弧度/秒, 确保速度受限。1250 * 2 * 3.1416 / 60 = 130.9
- `dev0.axis0.controller.config.pos_gain = 20.0`
  - 设置合适的比例增益。
- `dev0.axis0.controller.config.vel_gain = 0.05`
  - 根据电机特性设定速度环增益。
- `dev0.axis0.controller.config.vel_integrator_gain = 0.1`
  - 设定速度积分增益, 确保稳定性。
#### 1.5 梯形加减速配置
- `dev0.axis0.trap_traj.config.vel_limit = 100`
  - 限制速度在最大转速范围内。1250 * 2 * 3.1416 / 60 = 130.9
- `dev0.axis0.trap_traj.config.accel_limit = 5`
  - 限制加速度, 避免电机启动时电流过冲。
- `dev0.axis0.trap_traj.config.decel_limit = 5`
  - 限制减速度, 保护电机和驱动器。
- `dev0.axis0.controller.config.input_mode = INPUT_MODE_TRAP_TRAJ`
  - 使用梯形轨迹作为输入模式, 确保平滑加减速。
#### 1.6 保存配置
- `dev0.save_configuration()`
- `dev0.reboot()`

### 2. 校准工作
注意：进行参数校准前请确保电机转子能够自由旋转而且不能有偏载，即负载均匀和较弱的摩擦负载才行，重载或类似弹簧载荷不行，否则将影响参数自动校准
> 清除错误: `dump_errors(dev0, True)` `dev0.clear_errors()`
> 一键: `dev0.axis0.requested_state = AXIS_STATE_STARTUP_SEQUENCE` `dev0.axis0.requested_state = AXIS_STATE_FULL_CALIBRATION_SEQUENCE`
#### 2.1 校准电机
- `dev0.axis0.requested_state = AXIS_STATE_MOTOR_CALIBRATION`
- `dump_errors(dev0)`
  - 列出状态信息，如果返回状态没有错误则编码器索引校准OK，可以继续进行下面步骤，如果出现错误则要根据错误信息分析原因，然后清除错误后重新尝试
- `dev0.axis0.motor.config.pre_calibrated = True`
#### 2.2 编码器校准
- `dev0.axis0.requested_state = AXIS_STATE_ENCODER_INDEX_SEARCH`
  - 索引校准时电机的转动方向(以下三个参数正负号应保持一致)
  - `dev0.axis0.config.calibration_lockin.ramp_distance = -3.14159`
  - `dev0.axis0.config.calibration_lockin.accel = -10`
  - `dev0.axis0.config.calibration_lockin.vel = -20`
- `dump_errors(dev0)`
- `dev0.axis0.requested_state = AXIS_STATE_ENCODER_OFFSET_CALIBRATION`
- `dump_errors(dev0)`
- `dev0.axis0.encoder.config.pre_calibrated = True`
#### 2.3 保存校准结果
- `dev0.save_configuration()`
- `dev0.reboot()`

### 3. 控制电机运行
- `dev0.axis0.requested_state = AXIS_STATE_ENCODER_INDEX_SEARCH`
- `dev0.axis0.requested_state = AXIS_STATE_CLOSED_LOOP_CONTROL`
- `dev0.axis0.controller.input_pos = 50`
- `dev0.axis0.requested_state = AXIS_STATE_IDLE`

### 4. 如何避免每次重新启动后手动编码器索引校准、进入闭环控制
- `dev0.axis0.config.startup_encoder_index_search = True`
- `dev0.axis0.config.startup_closed_loop_control = True`
- `dev0.save_configuration()`

### 5. ODrive 配置参数备份
- 将配置以文件的形式保存到PC上:
  - `odrivetool backup-config foc_config.json`
- 从配置文件还原到配置到ODrive:
  - `odrivetool restore-config foc_config.json`

```
dev0.erase_configuration()
dev0.reboot()
```

```
dev0.config.brake_resistance = 0
dev0.config.dc_bus_undervoltage_trip_level = 20
dev0.config.dc_bus_overvoltage_trip_level = 30
dev0.config.dc_max_positive_current = 40
dev0.config.dc_max_negative_current = -2
dev0.config.max_regen_current = 2
```

```
dev0.axis0.motor.config.pole_pairs = 11
dev0.axis0.motor.config.calibration_current = 2
dev0.axis0.motor.config.resistance_calib_max_voltage = 10
dev0.axis0.motor.config.motor_type = MOTOR_TYPE_HIGH_CURRENT
dev0.axis0.motor.config.current_lim = 2
dev0.axis0.motor.config.requested_current_range = 20
dev0.axis0.motor.config.torque_constant = 0.20

dev0.axis0.encoder.config.mode = ENCODER_MODE_INCREMENTAL
dev0.axis0.encoder.config.use_index = True
dev0.axis0.encoder.config.cpr = -4096
dev0.axis0.encoder.config.bandwidth = 2000
dev0.axis0.config.calibration_lockin.current = 0.5
dev0.axis0.config.calibration_lockin.ramp_time = 0.5
dev0.axis0.config.calibration_lockin.ramp_distance = 3.14159
dev0.axis0.config.calibration_lockin.accel = 10
dev0.axis0.config.calibration_lockin.vel = 20

dev0.axis0.controller.config.control_mode = CONTROL_MODE_VELOCITY_CONTROL
dev0.axis0.controller.config.vel_limit = 100
dev0.axis0.controller.config.pos_gain = 20.0
dev0.axis0.controller.config.vel_gain = 0.05
dev0.axis0.controller.config.vel_integrator_gain = 0.1
dev0.axis0.trap_traj.config.vel_limit = 100
dev0.axis0.trap_traj.config.accel_limit = 5
dev0.axis0.trap_traj.config.decel_limit = 5
dev0.axis0.controller.config.input_mode = INPUT_MODE_TRAP_TRAJ

### 2. 校准工作
dump_errors(dev0, True) # dev0.clear_errors()
dev0.axis0.requested_state = AXIS_STATE_MOTOR_CALIBRATION
dump_errors(dev0)
dev0.axis0.motor.config.pre_calibrated = True
dev0.axis0.requested_state = AXIS_STATE_ENCODER_INDEX_SEARCH
dump_errors(dev0)
dev0.axis0.requested_state = AXIS_STATE_ENCODER_OFFSET_CALIBRATION
dump_errors(dev0)
dev0.axis0.encoder.config.pre_calibrated = True
dev0.save_configuration()
dev0.reboot()

### 3. 控制电机运行
dev0.axis0.requested_state = AXIS_STATE_ENCODER_INDEX_SEARCH
dev0.axis0.requested_state = AXIS_STATE_CLOSED_LOOP_CONTROL
dev0.axis0.controller.input_pos = 50
dev0.axis0.requested_state = AXIS_STATE_IDLE

### 4. 如何避免每次重新启动后手动编码器索引校准、进入闭环控制
dev0.axis0.config.startup_encoder_index_search = True
dev0.axis0.config.startup_closed_loop_control = True
dev0.save_configuration()
```

```
dev0.axis1.motor.config.pole_pairs = 11
dev0.axis1.motor.config.calibration_current = 2
dev0.axis1.motor.config.resistance_calib_max_voltage = 10
dev0.axis1.motor.config.motor_type = MOTOR_TYPE_HIGH_CURRENT
dev0.axis1.motor.config.current_lim = 2
dev0.axis1.motor.config.requested_current_range = 20
dev0.axis1.motor.config.torque_constant = 0.20

dev0.axis1.encoder.config.mode = ENCODER_MODE_INCREMENTAL
dev0.axis1.encoder.config.use_index = True
dev0.axis1.encoder.config.cpr = -4096
dev0.axis1.encoder.config.bandwidth = 2000
dev0.axis1.config.calibration_lockin.current = 0.5
dev0.axis1.config.calibration_lockin.ramp_time = 0.5
dev0.axis1.config.calibration_lockin.ramp_distance = 3.14159
dev0.axis1.config.calibration_lockin.accel = 10
dev0.axis1.config.calibration_lockin.vel = 20

dev0.axis1.controller.config.control_mode = CONTROL_MODE_VELOCITY_CONTROL
dev0.axis1.controller.config.vel_limit = 100
dev0.axis1.controller.config.pos_gain = 20.0
dev0.axis1.controller.config.vel_gain = 0.05
dev0.axis1.controller.config.vel_integrator_gain = 0.1
dev0.axis1.trap_traj.config.vel_limit = 100
dev0.axis1.trap_traj.config.accel_limit = 5
dev0.axis1.trap_traj.config.decel_limit = 5
dev0.axis1.controller.config.input_mode = INPUT_MODE_TRAP_TRAJ

### 2. 校准工作
dump_errors(dev0, True) # dev0.clear_errors()
dev0.axis1.requested_state = AXIS_STATE_MOTOR_CALIBRATION
dump_errors(dev0)
dev0.axis1.motor.config.pre_calibrated = True
dev0.axis1.requested_state = AXIS_STATE_ENCODER_INDEX_SEARCH
dump_errors(dev0)
dev0.axis1.requested_state = AXIS_STATE_ENCODER_OFFSET_CALIBRATION
dump_errors(dev0)
dev0.axis1.encoder.config.pre_calibrated = True
dev0.save_configuration()
dev0.reboot()

### 3. 控制电机运行
dev0.axis1.requested_state = AXIS_STATE_ENCODER_INDEX_SEARCH
dev0.axis1.requested_state = AXIS_STATE_CLOSED_LOOP_CONTROL
dev0.axis1.controller.input_pos = 50
dev0.axis1.requested_state = AXIS_STATE_IDLE

### 4. 如何避免每次重新启动后手动编码器索引校准、进入闭环控制
dev0.axis1.config.startup_encoder_index_search = True
dev0.axis1.config.startup_closed_loop_control = True
dev0.save_configuration()
```

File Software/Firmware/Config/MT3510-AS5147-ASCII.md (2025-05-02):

## MT3510-AS5147-ASCII

### Calibration

```
sc
w axis0.requested_state 7
w axis1.requested_state 7
```

### IDLE Mode
```
w axis0.requested_state 1
w axis1.requested_state 1
```

### Loop Control Mode: Velocity Control 

`v motor velocity current_ff`
`v` 表示速度控制模式
`motor` 表示电机编号, 0 或 1
`velocity` 目标转速，单位为 counts/s
`current_ff` 电流前馈, 单位为 A（可选的）

> 请注意，如果您不了解前馈和它的作用，只需将其忽略即可。以上命令发送后会触发对应电机的内部看门狗喂狗动作。

```
w axis0.requested_state 8
w axis1.requested_state 8
v 0 2.0 0.0
v 1 2.0 0.0
```

### Loop Control Mode: Position Control 

`q motor position velocity_lim current_lim`
`q` 表示位置控制模式
`motor` 表示电机编号, 0 或 1
`position` 目标位置，值表示编码器的计数
`velocity_lim` 转速限制，单位为counts/s （可选的）
`current_lim` 电流限制，单位为A（可选的）

> 请注意，如果您不了解前馈和它的作用，只需将其忽略即可。以上命令发送后会触发对应电机的内部看门狗喂狗动作。

```
w axis0.requested_state 8
w axis1.requested_state 8
q 0 50 100 10
q 0 50 100 10
```

### Servo

`m servo angle`

`m 0 110 1 80 2 70 3 100`

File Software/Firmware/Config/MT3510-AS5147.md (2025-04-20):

## Motor Configuration
[Odrive 云台电机配置实例](https://blog.csdn.net/qq_42731705/article/details/115433990)

### Odrive 参数
| 参数 | Odrive |
|---|---|
| 版本 | ODrive 3.6-24V  |

### 锂电池参数
| 参数 | 锂电池 |
|---|---|
| 电池容量 | 3.0Ah |
| 输出电流 | 5 A |
| 输出电压 | 24 V |

### 编码器参数
| 参数 | AS5147P |
|---|---|
| CPR | 4096 |
| PPR | 1024 |

### PM3510 参数
| 参数 | PM3510 |
|---|---|
| 额定电压 (Nominal voltage)  | 12 V |
| 额定电流 (Nominal current)  | 0.53 A |
| 额定扭矩 (Nominal torque) | 0.11 N.M |
| 额定转速 (Nominal Speed) | 945 rpm |
| 最大转速 (Max Speed) | 1250 rpm |
| 堵转扭矩 (Stall torque) | 0.16 N.M |
| 堵转电流 (Stall current) | 0.80 A |
| 相间电阻 (Phase to phase resistance) | 7.8 |
| 相间电感 (Phase to phase inductance) | 3.95 Mh |
| 转速常数 (Speed constant) | 45 rpm/V |
| 扭矩常数 (Torque constant)  | 0.20 N.M/A |
| 转子惯量 (Rotor inertia) | 81 gm² |
| 极对数 (Number of poles) | 11 |
| 电机重量 (Motor weight) | 73 g |
| 工作温度范围 (Working temperature) | -20 / 80 ℃ |
| 最高退磁温度 (Max demagnetize temperature) | 120 ℃ |
| 定子尺寸 (Stator dimension (D×L)) | 35×10 |
| 绕线圈数 (Turns) | 36 |
| 滑环尺寸 (Slipring) | 12.5 mm |

### 1. 配置参数
> 进行配置前建议首先执行一遍擦除配置:
> dev0.erase_configuration()
#### 1.1 基本配置
- `dev0.config.brake_resistance = 0`
  - PM3510 电机的功率较小, 且使用锂电池供电, 不需要外部刹车电阻。
- `dev0.config.dc_bus_undervoltage_trip_level = 20`
  - 锂电池输出电压为 24V, 考虑放电特性, 设置欠压保护在 20V 可避免过放。
- `dev0.config.dc_bus_overvoltage_trip_level = 30`
  - 保护 ODrive 电路, 避免电压瞬间超过 ODrive 的额定电压范围24V。
- `dev0.config.dc_max_positive_current = 60`
  - 限制最大正向电流为锂电池输出电流 60A, 避免过流损坏电池和 ODrive。
- `dev0.config.dc_max_negative_current = -2`
  - 允许轻微的再生电流回灌, 避免过度充电电池。
- `dev0.config.max_regen_current = 2`
  - 限制再生电流, 保护电池不被回灌过多电流。开关电源进行供电所以不具备电能回收功能。(小于 4A)
- `dev0.servo0.config.servo_init_angle = 90`
- `dev0.servo1.config.servo_init_angle = 90`
- `dev0.servo2.config.servo_init_angle = 90`
- `dev0.servo3.config.servo_init_angle = 90`
  - 设置初始角度为 90°, 使得云台初始位置为水平。

- `dev0.save_configuration()`
#### 1.2 电机配置
- `dev0.axis0.motor.config.pole_pairs = 11`
  - PM3510 电机的极对数为 11。
- `dev0.axis0.motor.config.calibration_current = 2`
  - 设置校准电流为 2A, 避免过热或损坏电机。
- `dev0.axis0.motor.config.resistance_calib_max_voltage = 5`
  - 电机的相间电阻较高(7.8Ω)，调整calibration_current和resistance_calib_max_voltage。
- `dev0.axis0.motor.config.motor_type = MOTOR_TYPE_GIMBAL`
  - PM3510 是无刷云台直流电机, 适合使用该模式。云台电机：MOTOR_TYPE_GIMBAL；大电流电机：MOTOR_TYPE_HIGH_CURRENT。
- `dev0.axis0.motor.config.current_lim = 4`
  - 限制最大电流在 2A, 匹配电机堵转电流, 避免电机过载。
- `dev0.axis0.motor.config.requested_current_range = 60`
  - 设定电流范围为 40A, 满足电机需求并保持电流采样稳定。
- `dev0.axis0.motor.config.torque_constant = 0.20`
  - 设置扭矩常数为 0.20 N.M/A, 匹配 PM3510 电机特性。
- `dev0.axis0.motor.fet_thermistor.config.temp_limit_upper = 150`
  - 使用的温敏电阻不同，稍加提高温度上限。
#### 1.3 编码器配置
- `dev0.axis0.encoder.config.mode = ENCODER_MODE_INCREMENTAL`
  - AS5147P 为增量式编码器, 使用增量模式。
- `dev0.axis0.encoder.config.use_index = False`
  - 使用索引信号进行初始化。
- `dev0.axis0.encoder.config.cpr = 2048`
  - AS5147P 编码器 CPR 为 2048。
- `dev0.axis0.encoder.config.bandwidth = 3000`
  - 设置编码器带宽为 3000Hz, 可滤除噪声且保持响应速度。
- `dev0.axis0.config.calibration_lockin.current = 2`
  - 使用 2A 校准电流, 避免电机过热。
- `dev0.axis0.config.calibration_lockin.ramp_time = 0.5`
  - 0.5 秒的斜坡时间让电流缓慢上升, 减少电机冲击。
- `dev0.axis0.config.calibration_lockin.ramp_distance = 3.14159`
  - 让电机旋转半圈（π弧度）确保充分校准。
- `dev0.axis0.config.calibration_lockin.accel = 10`
  - 设定加速度, 确保电机稳定旋转。
- `dev0.axis0.config.calibration_lockin.vel = 20`
  - 校准时设定速度为 20 rad/s。
#### 1.4 控制器配置
- `dev0.axis0.controller.config.control_mode = CONTROL_MODE_POSITION_CONTROL`
  - 选择位置控制模式。
- `dev0.axis0.controller.config.vel_limit = 60`
  - 将最大转速 1250 rpm 转换为弧度/秒, 确保速度受限。1250 * 2 * 3.1416 / 60 = 130.9
- `dev0.axis0.controller.config.pos_gain = 50.0`
  - 设置合适的比例增益。
- `dev0.axis0.controller.config.vel_gain = 0.2`
  - 根据电机特性设定速度环增益。
- `dev0.axis0.controller.config.vel_integrator_gain = 1`
  - 设定速度积分增益, 确保稳定性。
- `dev0.axis0.controller.config.vel_limit_tolerance = 1000`
  - 电机限速。
#### 1.5 梯形加减速配置
- `dev0.axis0.trap_traj.config.vel_limit = 60`
  - 限制速度在最大转速范围内。1250 * 2 * 3.1416 / 60 = 130.9
- `dev0.axis0.trap_traj.config.accel_limit = 5`
  - 限制加速度, 避免电机启动时电流过冲。
- `dev0.axis0.trap_traj.config.decel_limit = 5`
  - 限制减速度, 保护电机和驱动器。
- `dev0.axis0.controller.config.input_mode = INPUT_MODE_TRAP_TRAJ`
  - 使用梯形轨迹作为输入模式, 确保平滑加减速。
#### 1.6 保存配置
- `dev0.save_configuration()`

### 2. 校准工作
注意：进行参数校准前请确保电机转子能够自由旋转而且不能有偏载，即负载均匀和较弱的摩擦负载才行，重载或类似弹簧载荷不行，否则将影响参数自动校准
> 清除错误: `dump_errors(dev0, True)` `dev0.clear_errors()`
> 一键: `dev0.axis0.requested_state = AXIS_STATE_STARTUP_SEQUENCE` `dev0.axis0.requested_state = AXIS_STATE_FULL_CALIBRATION_SEQUENCE`
#### 2.1 校准电机
- `dev0.axis0.requested_state = AXIS_STATE_MOTOR_CALIBRATION`
- `dump_errors(dev0)`
  - 列出状态信息，如果返回状态没有错误则编码器索引校准OK，可以继续进行下面步骤，如果出现错误则要根据错误信息分析原因，然后清除错误后重新尝试
- `dev0.axis0.motor.config.pre_calibrated = True`
#### 2.2 编码器校准
- `dev0.axis0.requested_state = AXIS_STATE_ENCODER_INDEX_SEARCH`
  - 索引校准时电机的转动方向(以下三个参数正负号应保持一致)
  - `dev0.axis0.config.calibration_lockin.ramp_distance = -3.14159`
  - `dev0.axis0.config.calibration_lockin.accel = -10`
  - `dev0.axis0.config.calibration_lockin.vel = -20`
- `dump_errors(dev0)`
- `dev0.axis0.requested_state = AXIS_STATE_ENCODER_OFFSET_CALIBRATION`
- `dump_errors(dev0)`
- `dev0.axis0.encoder.config.pre_calibrated = True`
#### 2.3 保存校准结果
- `dev0.save_configuration()`

### 3. 切换电机类型
- `dev0.axis0.motor.config.motor_type = MOTOR_TYPE_GIMBAL`
- `dev0.save_configuration()`

### 4. 控制电机运行
- `dev0.axis0.requested_state = AXIS_STATE_CLOSED_LOOP_CONTROL`
- `dev0.axis0.controller.input_pos = 10`
- `dev0.axis0.requested_state = AXIS_STATE_IDLE`

### 5. 如何避免每次重新启动后手动编码器索引校准、进入闭环控制
- `dev0.axis0.config.startup_closed_loop_control = True`
- `dev0.save_configuration()`

### 6. PID参数调节
```
dump_errors(dev0, True)
dev0.axis0.requested_state = AXIS_STATE_ENCODER_OFFSET_CALIBRATION

dev0.axis0.controller.config.input_mode = INPUT_MODE_PASSTHROUGH
dev0.axis0.controller.config.control_mode = CONTROL_MODE_VELOCITY_CONTROL
dev0.axis0.requested_state = AXIS_STATE_CLOSED_LOOP_CONTROL
dev0.axis0.controller.input_vel = 5

dev0.axis0.controller.config.pos_gain = 50
dev0.axis0.controller.config.vel_gain = 0.2
dev0.axis0.controller.config.vel_integrator_gain = 1

dev0.axis0.requested_state = AXIS_STATE_IDLE
```

### 7. ODrive 配置参数备份
- 将配置以文件的形式保存到PC上:
  - `odrivetool backup-config foc_config.json`
- 从配置文件还原到配置到ODrive:
  - `odrivetool restore-config foc_config.json`

```
dev0.erase_configuration()

dev0.config.brake_resistance = 0
dev0.config.dc_bus_undervoltage_trip_level = 20
dev0.config.dc_bus_overvoltage_trip_level = 30
dev0.config.dc_max_positive_current = 60
dev0.config.dc_max_negative_current = -2
dev0.config.max_regen_current = 2

dev0.save_configuration()
```

```
dev0.axis0.motor.config.pole_pairs = 11
dev0.axis0.motor.config.calibration_current = 2
dev0.axis0.motor.config.resistance_calib_max_voltage = 5
dev0.axis0.motor.config.motor_type = MOTOR_TYPE_HIGH_CURRENT
dev0.axis0.motor.config.current_lim = 4
dev0.axis0.motor.config.requested_current_range = 60
dev0.axis0.motor.config.torque_constant = 0.20
dev0.axis0.motor.fet_thermistor.config.temp_limit_upper = 150
dev0.axis0.encoder.config.mode = ENCODER_MODE_INCREMENTAL
dev0.axis0.encoder.config.use_index = False
dev0.axis0.encoder.config.cpr = 2048
dev0.axis0.encoder.config.bandwidth = 3000
dev0.axis0.config.calibration_lockin.current = 2
dev0.axis0.config.calibration_lockin.ramp_time = 0.5
dev0.axis0.config.calibration_lockin.ramp_distance = 3.14159
dev0.axis0.config.calibration_lockin.accel = 10
dev0.axis0.config.calibration_lockin.vel = 20
dev0.axis0.controller.config.control_mode = CONTROL_MODE_POSITION_CONTROL
dev0.axis0.controller.config.vel_limit = 60
dev0.axis0.controller.config.pos_gain = 50
dev0.axis0.controller.config.vel_gain = 0.2
dev0.axis0.controller.config.vel_integrator_gain = 5
dev0.axis0.controller.config.vel_limit_tolerance = 1000
dev0.axis0.trap_traj.config.vel_limit = 60
dev0.axis0.trap_traj.config.accel_limit = 5
dev0.axis0.trap_traj.config.decel_limit = 5
dev0.axis0.controller.config.input_mode = INPUT_MODE_TRAP_TRAJ

dev0.axis1.motor.config.pole_pairs = 11
dev0.axis1.motor.config.calibration_current = 2
dev0.axis1.motor.config.resistance_calib_max_voltage = 5
dev0.axis1.motor.config.motor_type = MOTOR_TYPE_HIGH_CURRENT
dev0.axis1.motor.config.current_lim = 4
dev0.axis1.motor.config.requested_current_range = 60
dev0.axis1.motor.config.torque_constant = 0.20
dev0.axis1.motor.fet_thermistor.config.temp_limit_upper = 150
dev0.axis1.encoder.config.mode = ENCODER_MODE_INCREMENTAL
dev0.axis1.encoder.config.use_index = False
dev0.axis1.encoder.config.cpr = 2048
dev0.axis1.encoder.config.bandwidth = 3000
dev0.axis1.config.calibration_lockin.current = 2
dev0.axis1.config.calibration_lockin.ramp_time = 0.5
dev0.axis1.config.calibration_lockin.ramp_distance = 3.14159
dev0.axis1.config.calibration_lockin.accel = 10
dev0.axis1.config.calibration_lockin.vel = 20
dev0.axis1.controller.config.control_mode = CONTROL_MODE_POSITION_CONTROL
dev0.axis1.controller.config.vel_limit = 60
dev0.axis1.controller.config.pos_gain = 50.0
dev0.axis1.controller.config.vel_gain = 0.2
dev0.axis1.controller.config.vel_integrator_gain = 5
dev0.axis1.controller.config.vel_limit_tolerance = 1000
dev0.axis1.trap_traj.config.vel_limit = 60
dev0.axis1.trap_traj.config.accel_limit = 5
dev0.axis1.trap_traj.config.decel_limit = 5
dev0.axis1.controller.config.input_mode = INPUT_MODE_TRAP_TRAJ

dev0.save_configuration()
```

```
dev0.axis0.requested_state = AXIS_STATE_FULL_CALIBRATION_SEQUENCE
dev0.axis1.requested_state = AXIS_STATE_FULL_CALIBRATION_SEQUENCE
dump_errors(dev0, True)
dev0.axis0.motor.config.pre_calibrated = True
dev0.axis0.encoder.config.pre_calibrated = True
dev0.axis1.motor.config.pre_calibrated = True
dev0.axis1.encoder.config.pre_calibrated = True
```

```
dev0.axis0.motor.config.motor_type = MOTOR_TYPE_GIMBAL
dev0.axis1.motor.config.motor_type = MOTOR_TYPE_GIMBAL
dev0.axis0.config.startup_closed_loop_control = True
dev0.axis1.config.startup_closed_loop_control = True
dev0.save_configuration()
```

```
dump_errors(dev0, True)
dev0.axis0.requested_state = AXIS_STATE_ENCODER_OFFSET_CALIBRATION
dev0.axis1.requested_state = AXIS_STATE_ENCODER_OFFSET_CALIBRATION

dev0.axis0.requested_state = AXIS_STATE_CLOSED_LOOP_CONTROL
dev0.axis1.requested_state = AXIS_STATE_CLOSED_LOOP_CONTROL
dev0.axis0.controller.input_pos = 10
dev0.axis1.controller.input_pos = 10

dev0.axis0.requested_state = AXIS_STATE_IDLE
dev0.axis1.requested_state = AXIS_STATE_IDLE

dev0.axis0.controller.config.input_mode = INPUT_MODE_PASSTHROUGH
dev0.axis1.controller.config.input_mode = INPUT_MODE_PASSTHROUGH
dev0.axis0.controller.config.control_mode = CONTROL_MODE_VELOCITY_CONTROL
dev0.axis1.controller.config.control_mode = CONTROL_MODE_VELOCITY_CONTROL
dev0.axis0.requested_state = AXIS_STATE_CLOSED_LOOP_CONTROL
dev0.axis1.requested_state = AXIS_STATE_CLOSED_LOOP_CONTROL
dev0.axis0.controller.input_vel = 1
dev0.axis1.controller.input_vel = 1

dev0.axis0.motor.fet_thermistor.config.enabled = False
dev0.axis1.motor.fet_thermistor.config.enabled = False
dev0.axis0.motor.fet_thermistor
dev0.axis1.motor.fet_thermistor
```

```
dev0.servo0.angle = 110
dev0.servo1.angle = 80
dev0.servo2.angle = 70
dev0.servo3.angle = 100
```

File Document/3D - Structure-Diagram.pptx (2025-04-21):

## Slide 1

Cover

Lidar

Base

Control

Servo

Servo

Servo

Servo

arm

arm

motor

Battery

Case

arm

arm

motor

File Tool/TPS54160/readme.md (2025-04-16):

### TPS54160 配置工具

[德州仪器官方设计工具](https://www.ti.com.cn/product/cn/TPS54160#tech-docs)

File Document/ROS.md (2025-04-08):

## ROS2 基础

### 安装ROS2
```wget http://fishros.com/install -O fishros && bash fishros```

### 创建工作空间和功能包
##### 创建工作空间
```mkdir -p xxx_ws/src && cd xxx_ws/src```
##### 创建Python功能包
```ros2 pkg create xxx --build-type ament_python --dependencies rclpy```
##### 创建C++功能包
```ros2 pkg create xxx --build-type ament_cmake --dependencies rclcpp```

### 编写节点
#### Python节点
1. xxx(功能包名)/xxx(功能包名) 目录下创建 python 文件
2. 修改 setup.py，添加内容:
```
        'console_scripts': [
            "node_name = xxx.xxxx:main" # xxx为功能包名, xxxx为节点文件名
        ],
```
#### C++节点
1. xxx(功能包名)/src 目录下创建 cpp 文件
2. 修改 CmakeLists.txt, 添加内容:
```
add_executable(node_name src/xxxx.cpp) # xxxx为节点文件名
ament_target_dependencies(node_name rclcpp)

install(TARGETS
  node_name
  DESTINATION lib/${PROJECT_NAME}
)
```

### 编译
```
colcon build
--symlink-install # 编译并创建软链接
--packages-select xxx # 只编译xxx包
--packages-up-to xxx # 编译xxx包及其依赖项
--packages-skip xxx # 跳过xxx包及其依赖项
```

### 运行节点
#### source环境
```source install/setup.bash```
#### 运行节点
```ros2 run xxx node_name # xxx为功能包名, node_name为节点文件名```

### ROS2 基础指令
| **操作**                   | **指令**                                                   |
|----------------------------|------------------------------------------------------------|
| **查看 ROS2 可用节点、参数、服务** | `ros2 node/param/service list`                       |
| **查看 ROS2 消息类型、主题、接口** | `ros2 msg/topic/interface list`                    |
| **查看 ROS2 可用节点信息**  | `ros2 node info /node_name`                                 |
| **查看 ROS2 可用消息类型信息** | `ros2 interface show /msg_type_name`                      |
| **查看 ROS2 可用参数信息**  | `ros2 param describe /node_name /param_name`                |
| **查看 ROS2 可用服务信息**  | `ros2 service info /service_name`                          |
| **查看 ROS2 可用主题信息**  | `ros2 topic info /topic_name`                              |
| **查看 ROS2 日志**          | `ros2 log`                                                 |
| **查看 ROS2 日志详细信息**  | `ros2 log config`                                          |
| **查看 ROS2 日志级别**      | `ros2 log level`                                           |
| **查看 ROS2 配置**          | `ros2 config`                                              |
| **查看 ROS2 配置详细信息**  | `ros2 config list`                                         |
| **查看 ROS2 配置项**        | `ros2 config get /node_name /param_name`                   |
| **设置 ROS2 配置项**        | `ros2 config set /node_name /param_name value`             |

查看 TF 树
```ros2 run rqt_tf_tree rqt_tf_tree```

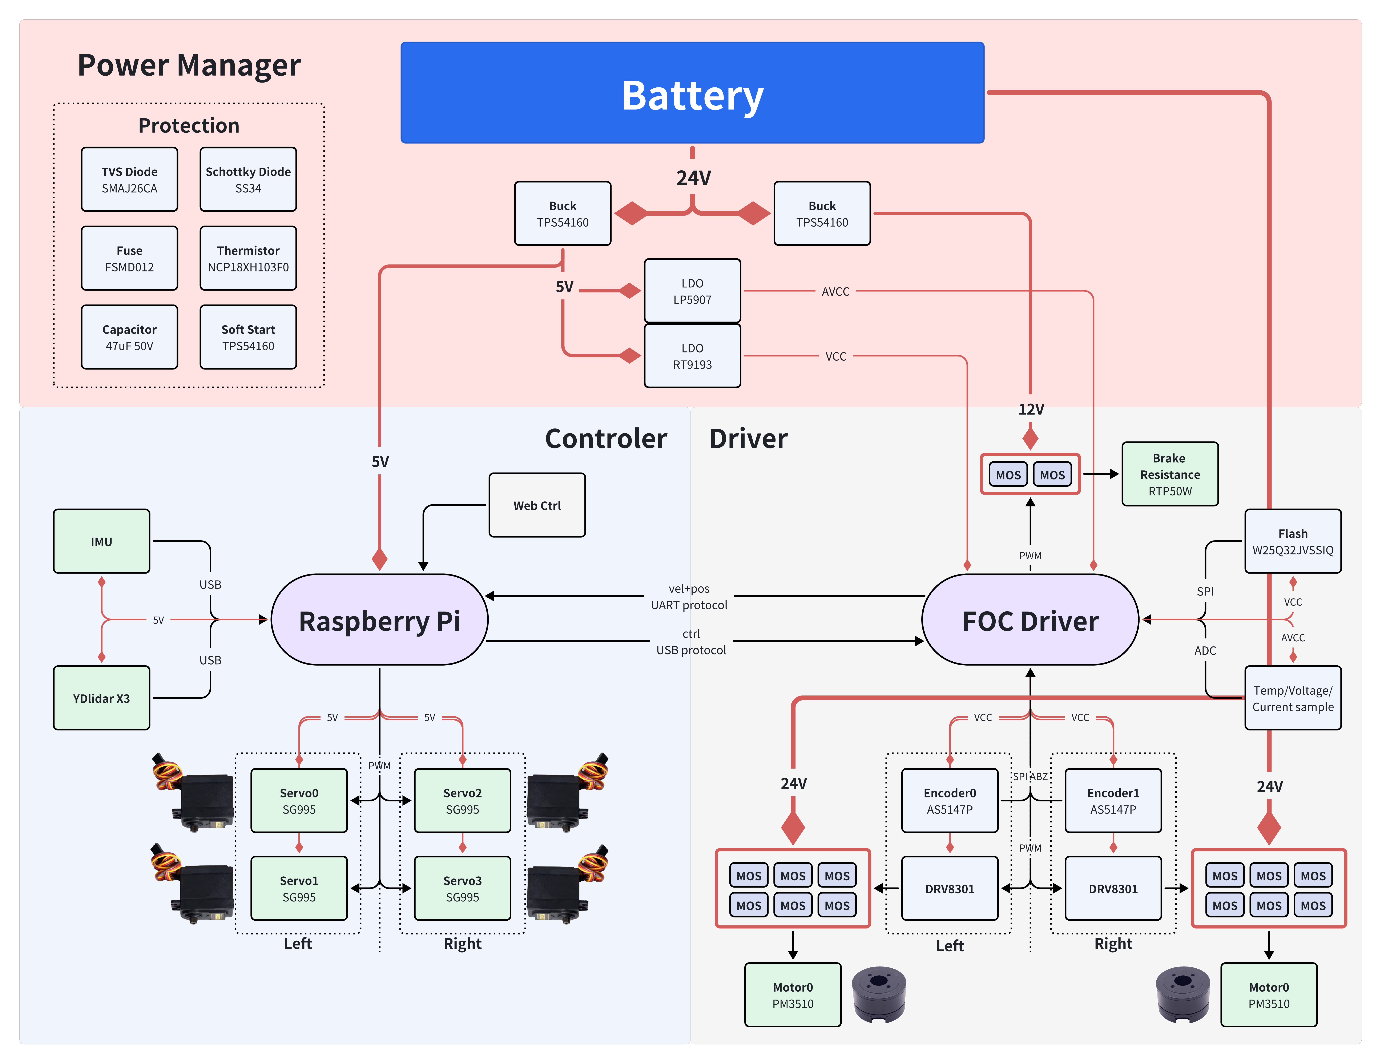
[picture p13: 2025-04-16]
Document/images/Hardware-Image.png

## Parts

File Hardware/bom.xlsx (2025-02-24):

Quantity | Comment | Designator | Footprint | Value | Purchase | 改 | 补买
8 | 82pF | C1,C4,C8,C9,C17,C19,C22,C24 | C0603 | 82pF | 立创商城
26 | 100nF | C2,C5,C7,C10,C11,C12,C13,C14,C15,C16,C18,C25,C36,C40,C43,C44,C50,C51,C57,C58,C66,C73,C74,C78,C81,C89 | C0603 | 100nF | 已购 |  | 100nF
3 | 1uF | C3,C37,C38 | C0603 | 1uF | 已购
13 | 2.2uF | C6,C20,C21,C49,C55,C59,C60,C65,C72,C80,C83,C85,C90 | C0603 | 2.2uF | 立创商城
9 | 2.2nF | C23,C61,C62,C63,C64,C82,C84,C86,C87 | C0603 | 2.2nF | 已购
12 | 47uF | C26,C27,C28,C29,C30,C31,C32,C33,C34,C35,C47,C70 | C1812 | 47uF | 淘宝 |  | 淘宝
2 | 10uF | C39,C42 | C0603 | 10uF | 立创商城
3 | 22nF | C41,C56,C79 | C0603 | 22nF
2 | 6.8pF | C45,C69 | C0603 | 6.8pF | 立创商城
1 | 3.3nF | C46 | C0603 | 3.3nF | 立创商城
1 | 5.1nF | C48 | C0603 | 5.1nF | 立创商城
6 | 40nF | C52,C53,C54,C75,C76,C77 | C0603 | 40nF | 立创商城 |  | 40nF
2 | 4.7uF | C67,C88 | C0603 | 4.7uF | 立创商城
1 | 6.8nF | C68 | C0603 | 6.8nF | 立创商城
1 | 4.7nF | C71 | C0603 | 4.7nF | 立创商城
2 | M1010RS-06P | CN1,CN3 | CONN-SMD_M1010RS-06P |  | 立创商城
2 | M1010RS-05P | CN4,CN5 | CONN-SMD_M1010RS-05P |  | 立创商城
1 | FPC09-Q1.0-6AH2.0 | CN7 | FPC-SMD_6P-P1.00_XYECONN_FPC09-Q1.0-6AH2.0 |  | 立创商城 |  | 6P 软排线
3 | SS34 | D1,D3,D4 | SMA_L4.4-W2.8-LS5.4-RD |  | 立创商城
1 | SMAJ30CA | D2 | SMA_L4.4-W2.6-LS5.0-BI |  | 立创商城
1 | FSMD012-1206-R | F1 | F1206 |  | 立创商城
2 | PZ254V-11-04P | H1,H2 | HDR-TH_4P-P2.54-V-M |  | 已购
1 | XT30U-M | H3 | XT30U-M |  | 淘宝
2 | MR30-M | H5,H6 | MR30-M |  | 淘宝
1 | 120uH | L1 | IND-SMD_L6.0-W6.0 | 120uH | 立创商城
1 | 22uH | L2 | IND-SMD_L6.0-W6.0 | 22uH | 立创商城
1 | YLED0603B | LED1 | LED0603_BLUE |  | 已购
2 | 2.54-2*20P | P1,P2 | MY_HDR-TH_40P-P2.54-V-M-R2-C20-S2.54 |  | 淘宝
1 | KRC116S-RTK/P | Q1 | SOT-23-3_L2.9-W1.6-P1.90-LS2.8-BR |  | 立创商城 | DTC143ZCA (https://item.szlcsc.com/15912.html?c=Q2)
12 | KNY3406C | Q2,Q3,Q4,Q5,Q6,Q7,Q8,Q9,Q10,Q11,Q12,Q13 | PDFNWB-8L_L6.0-W5.0-P1.27-BL-EP_CON |  | 立创商城 | TMN6080NF (https://item.szlcsc.com/8406197.html?c=Q2) | KNY3406C
16 | 3.3kΩ | R1,R2,R9,R10,R11,R13,R15,R18,R24,R25,R26,R38,R45,R46,R47,R57 | R0603 | 3.3kΩ | 已购
5 | 10kΩ | R3,R4,R14,R28,R44 | R0603 | 10kΩ | 已购
2 | 1kΩ | R5,R7 | R0603 | 1kΩ | 已购
6 | 22Ω | R6,R8,R39,R40,R52,R56 | R0603 | 22Ω | 立创商城
1 | 120Ω | R12 | R0603 | 120Ω | 立创商城 |  | 100Ω/0603
2 | 4.7kΩ | R16,R17 | R0603 | 4.7kΩ | 立创商城 |  | 4.7kΩ
1 | 3.3Ω | R19 | R0603 | 3.3Ω | 立创商城
1 | 10Ω | R20 | R0603 | 10Ω | 立创商城
1 | 0Ω | R21 | R0603 | 0Ω | 已购
1 | 562kΩ | R22 | R0603 | 562kΩ | 立创商城
1 | 140kΩ | R23 | R0603 | 140kΩ | 立创商城
1 | 133kΩ | R27 | R0603 | 133kΩ | 立创商城
12 | 2.2Ω | R29,R30,R31,R33,R34,R35,R49,R50,R51,R53,R54,R55 | R0603 | 2.2Ω | 立创商城
2 | 18kΩ | R32,R48 | R0603 | 18kΩ | 立创商城
4 | 0.5mΩ | R36,R37,R58,R59 | R2512 | 0.5mΩ | 立创商城 |  | 0.5mΩ
1 | 365kΩ | R41 | R0603 | 365kΩ | 立创商城
1 | 52.3kΩ | R42 | R0603 | 52.3kΩ | 立创商城
1 | 86.6kΩ | R43 | R0603 | 86.6kΩ | 立创商城
2 | 100Ω | RN1,RN2 | RES-ARRAY-SMD_0603-8P-L3.2-W1.6-BL | 100Ω | 立创商城
2 | NCP18XH103F03RB | RT1,RT2 | R0603 |  | 立创商城 | KNTC0603
1 | TS-1088R-02026 | SW1 | SW-SMD_L3.9-W3.0-P4.45 |  | 立创商城
1 | TM-4175-B-B | SW2 | SW-SMD_TM-4175-B-B |  | 立创商城
1 | 焊接式_TFT_1.14_135x240_13pin | TFT1 | 焊接式_TFT_1.14_135X240_13PIN |  | 淘宝
1 | CH340K | U1 | ESOP-10_L4.9-W3.9-P1.00-LS6.2-BL-EP |  | 淘宝 |  | CH340K/10
1 | SN65HVD232DR | U2 | SOIC-8_L5.0-W4.0-P1.27-LS6.0-BL |  | 淘宝
1 | W25Q32JVSSIQ | U3 | SOIC-8_L5.3-W5.3-P1.27-LS8.0-BL |  | 已购
1 | MPU-6050 | U4 | QFN-24_L4.0-W4.0-P0.50-BL-EP2.7 |  | 淘宝 |  | MPU-6050
1 | RT9193-33GB | U5 | SOT-23-5_L3.0-W1.7-P0.95-LS2.8-BR |  | 淘宝
1 | LP5907MFX-3.3/NOPB | U6 | SOT-23-5_L3.0-W1.7-P0.95-LS2.8-BR |  | 淘宝
1 | ZX-XH2.54-14PWT | U7 | CONN-SMD_14P-P2.50_KH-A2504-14AWB |  | 淘宝
2 | DRV8301DCAR | U8,U9 | HTSSOP-56_L14.0-W6.0-P0.50-LS8.0-BL |  | 淘宝
1 | STM32F405VGT6 | U10 | LQFP-100_L14.0-W14.0-P0.50-LS16.0-BL |  | 淘宝
1 | TYPE-C-31-M-12 | USBC1 | USB-C_SMD-TYPE-C-31-M-12 |  | 淘宝
1 | 8MHz | X1 | OSC-SMD_3P-L3.2-W1.3-P1.20 | 8MHz | 淘宝

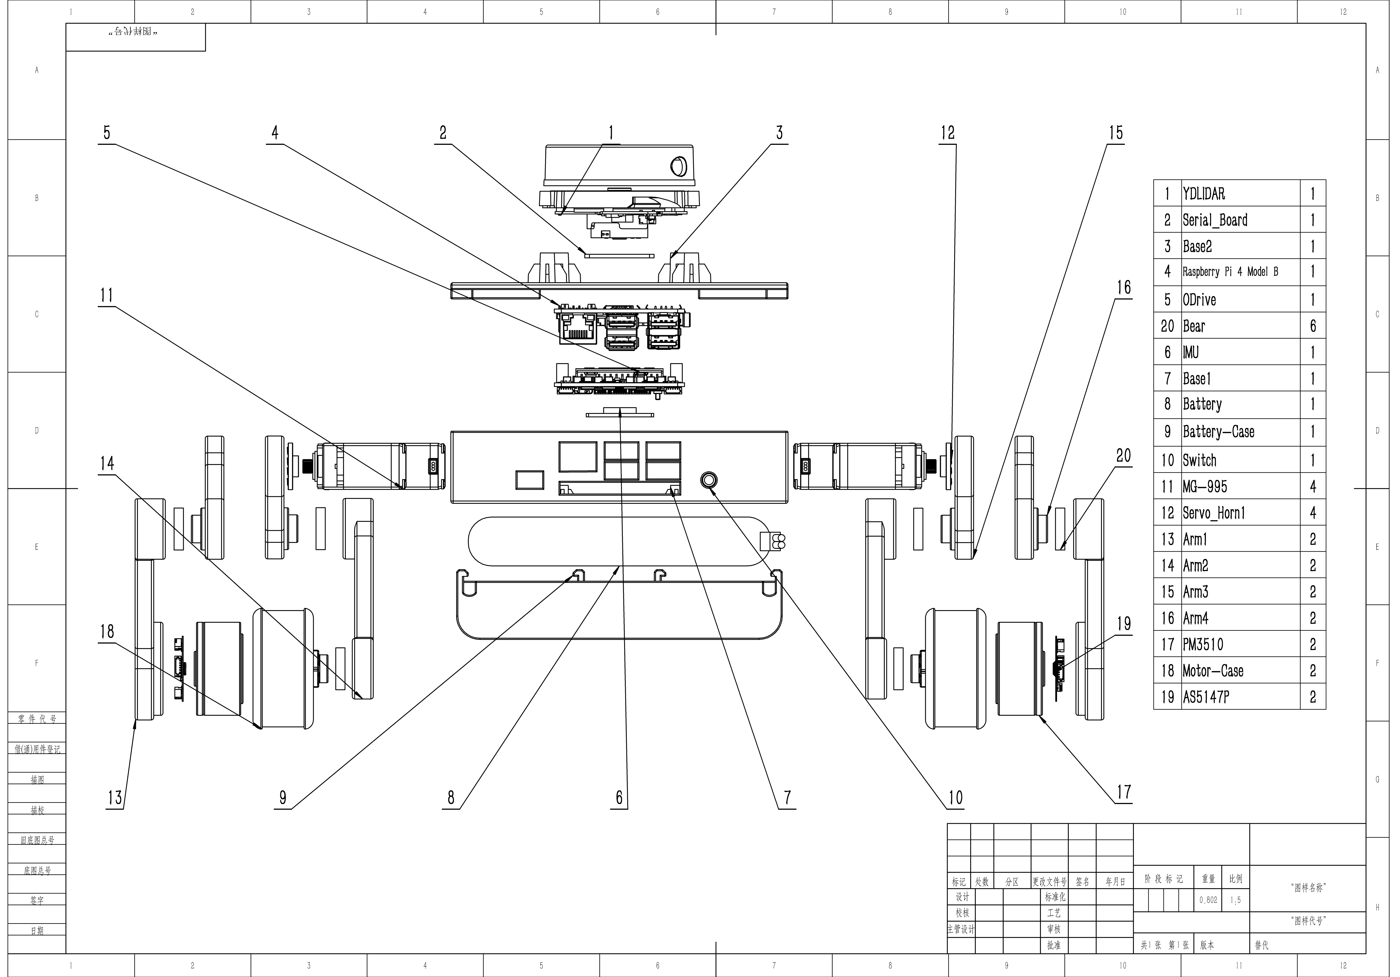
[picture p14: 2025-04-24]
Document/images/Structure_BOM.png

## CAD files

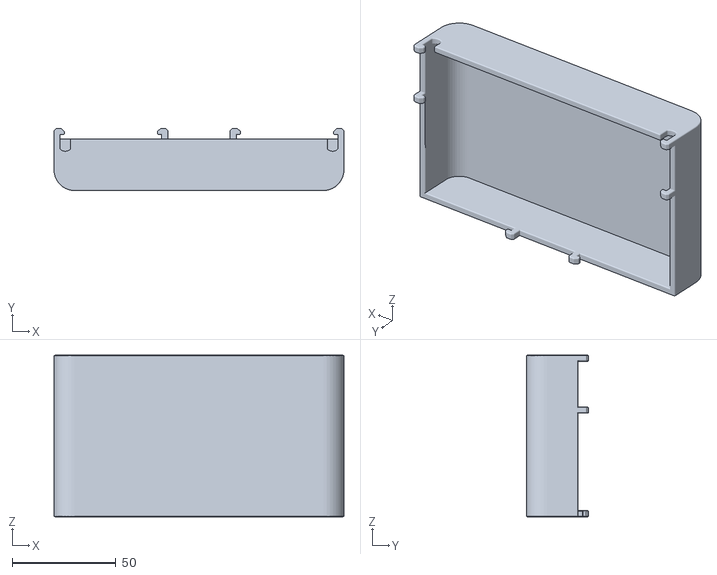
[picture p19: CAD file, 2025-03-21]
Model/Case/Case - Battery-Case-1.STL
140.0 x 30.0 x 78.0

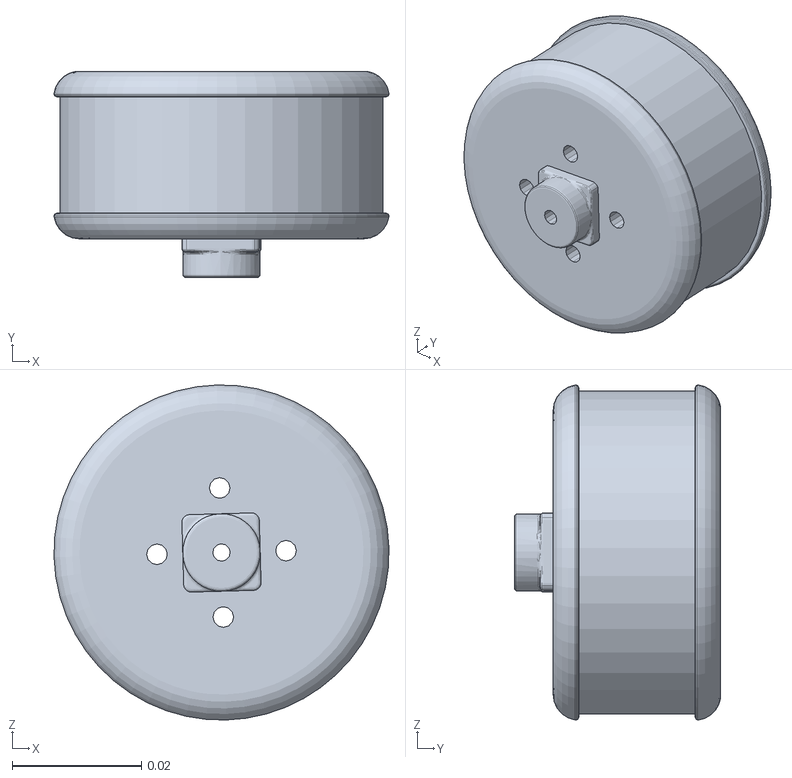
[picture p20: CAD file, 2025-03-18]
Software/ROS/wheel_robot_sim/src/wheel_robot/meshes/left_wheel_link.STL
0.0519 x 0.032 x 0.0519

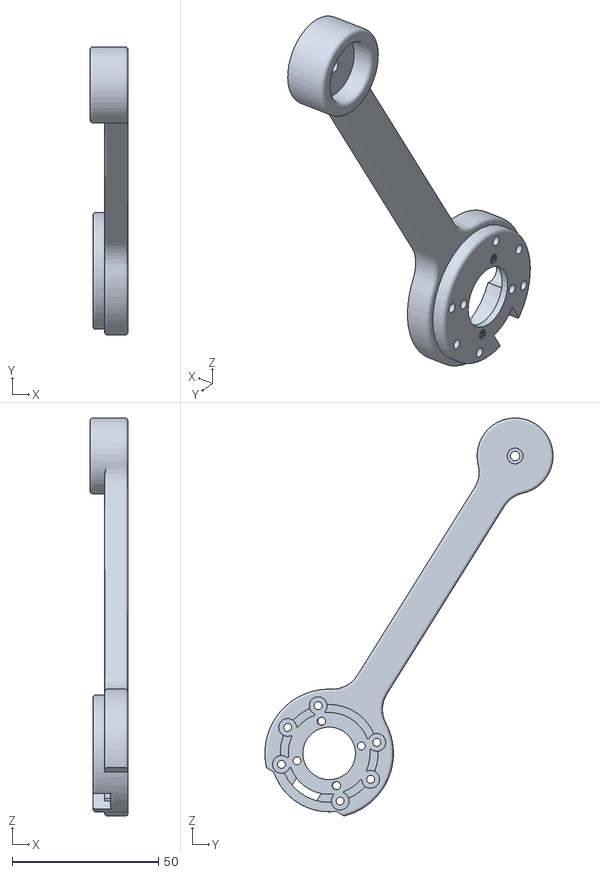
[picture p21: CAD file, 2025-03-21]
Model/Case/Case - Arm1-2.STL
13.0 x 98.6 x 136.2

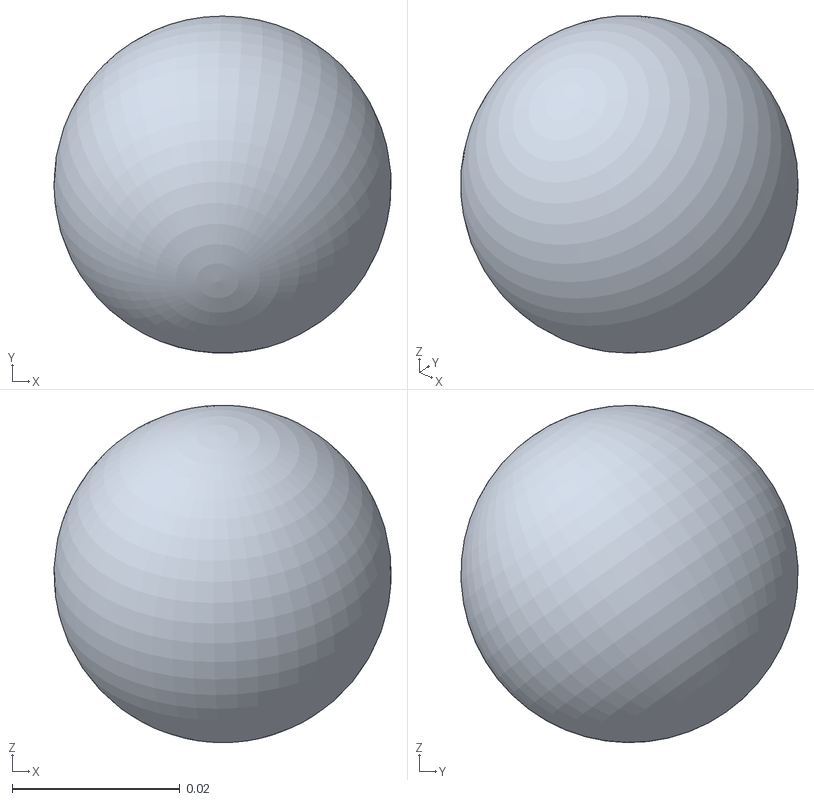
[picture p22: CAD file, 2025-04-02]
Model/ROS/Wheel_Robot_Sim_With_Caster/meshes/caster_link.STL
0.0402 x 0.0402 x 0.0403

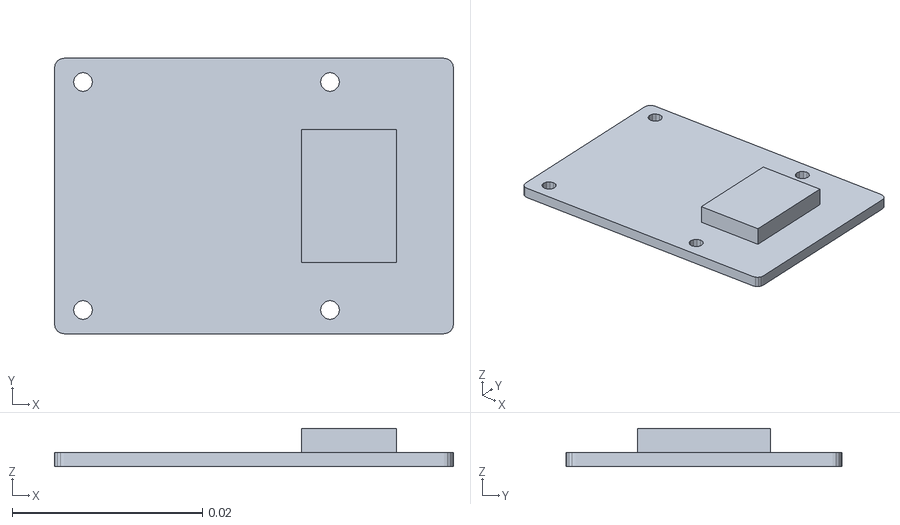
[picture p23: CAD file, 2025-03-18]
Software/ROS/wheel_robot_sim/src/wheel_robot/meshes/imu_link.STL
0.042 x 0.029 x 0.004

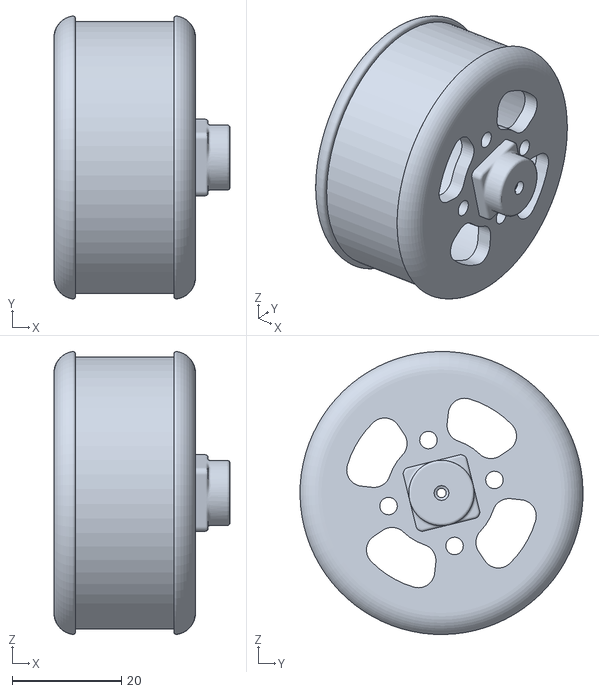
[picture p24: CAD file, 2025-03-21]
Model/Case/Case - Motor-Case-1.STL
32.3 x 51.9 x 51.9

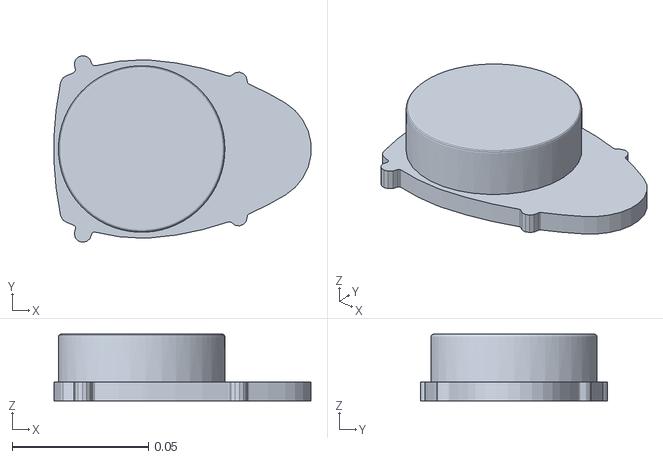
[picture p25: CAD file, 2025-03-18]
Software/ROS/wheel_robot_sim/src/wheel_robot/meshes/laser_link.STL
0.0942 x 0.0684 x 0.0245

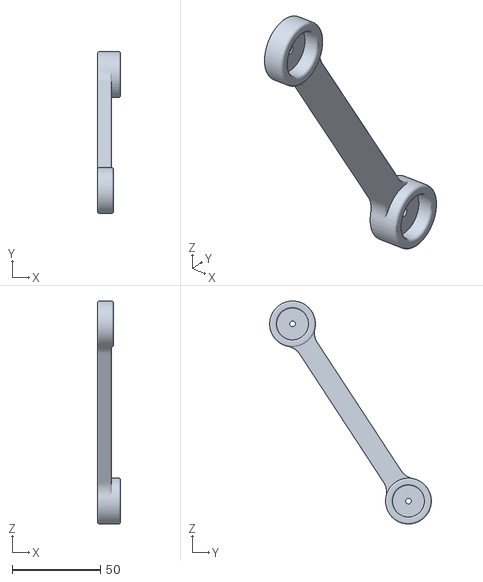
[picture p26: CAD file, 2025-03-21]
Model/Case/Case - Arm2-2.STL
13.0 x 91.7 x 126.4

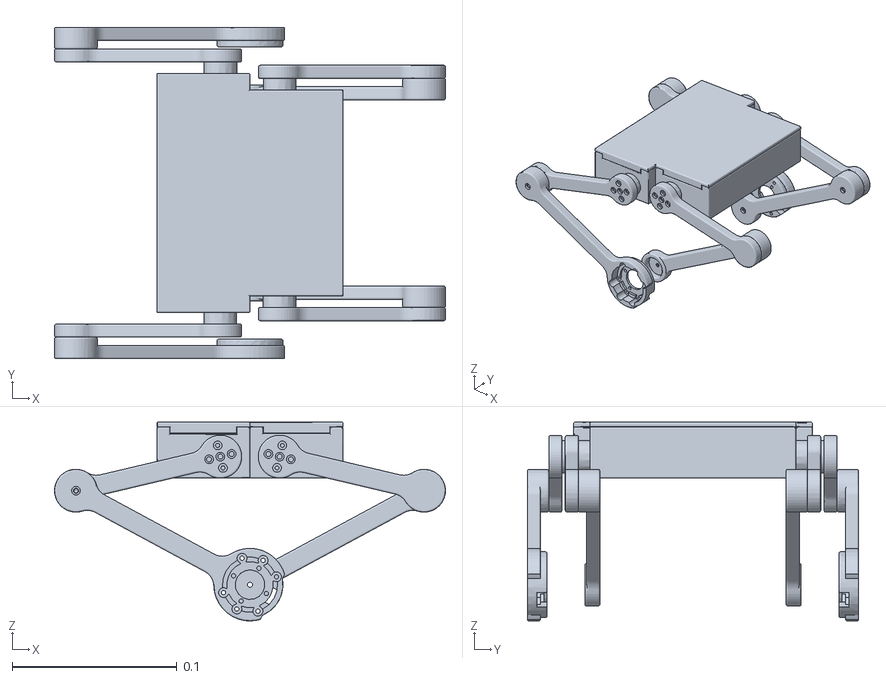
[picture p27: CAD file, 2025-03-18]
Software/ROS/wheel_robot_sim/src/wheel_robot/meshes/base_link.STL
0.237 x 0.201 x 0.121

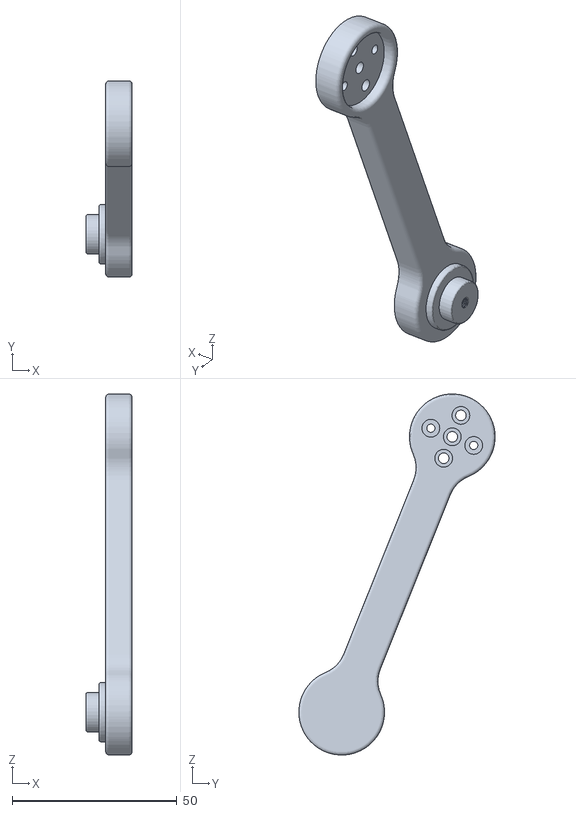
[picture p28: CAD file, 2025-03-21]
Model/Case/Case - Arm3-2.STL
14.0 x 59.5 x 109.5

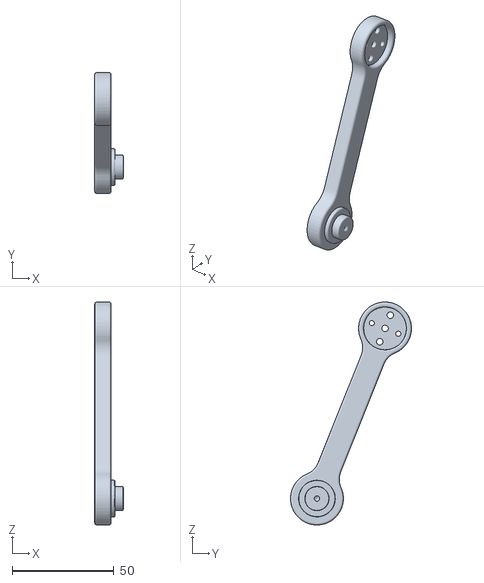
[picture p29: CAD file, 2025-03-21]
Model/Case/Case - Arm3-1.STL
14.0 x 59.4 x 109.5

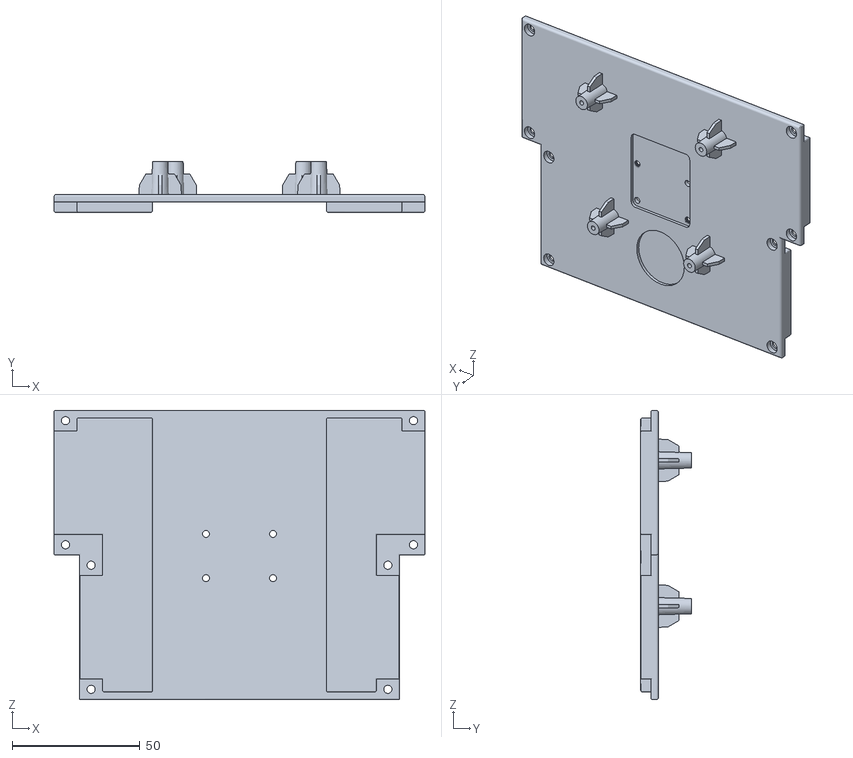
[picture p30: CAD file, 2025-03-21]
Model/Case/Case - Base2-2.STL
145.0 x 19.7 x 113.0

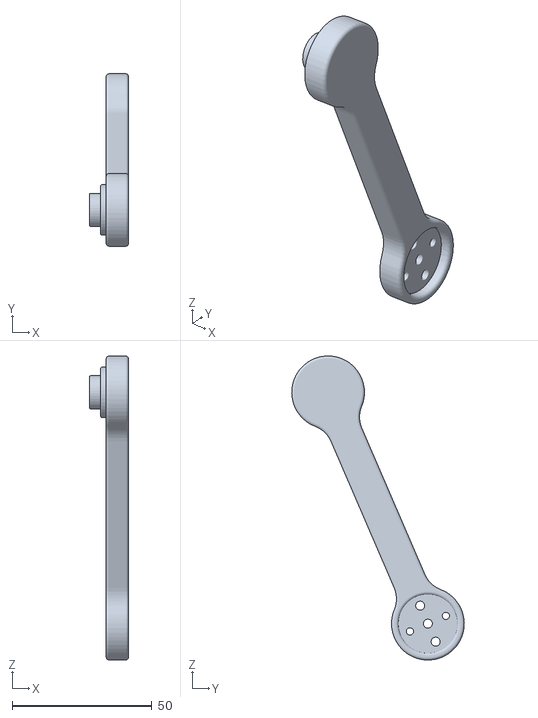
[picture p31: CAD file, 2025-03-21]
Model/Case/Case - Arm4-1.STL
14.0 x 61.6 x 108.6

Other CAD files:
Software/ROS/wheel_robot_sim/src/wheel_robot/meshes/right_wheel_link.STL
Model/Case/Case - Arm1-1.STL
Model/Case/Case - Arm2-1.STL
Model/Case/Case - Motor-Case-2.STL
Model/Case/Case - Arm4-2.STL
Model/Case/Case.STEP
Model/ROS/Wheel_Robot_Sim_With_Caster/meshes/base_link.STL
Model/ROS/Wheel_Robot_Sim_With_Caster/meshes/left_wheel_link.STL
Model/ROS/Wheel_Robot_Sim_With_Caster/meshes/right_wheel_link.STL

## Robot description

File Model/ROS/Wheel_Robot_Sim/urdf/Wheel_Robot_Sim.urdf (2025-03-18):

<?xml version="1.0" encoding="utf-8"?>
<!-- This URDF was automatically created by SolidWorks to URDF Exporter! Originally created by Stephen Brawner (brawner@gmail.com) 
     Commit Version: 1.6.0-4-g7f85cfe  Build Version: 1.6.7995.38578
     For more information, please see http://wiki.ros.org/sw_urdf_exporter -->
<robot name="Wheel_Robot_Sim">
  <link name="base_link">
    <inertial>
      <origin xyz="-0.00238065061006057 2.73588787687858E-09 0.0969110593365891" rpy="0 0 0" />
      <mass value="0.458809382377931" />
      <inertia ixx="0.000846411676685124" ixy="-1.77408502350691E-11" ixz="8.64502818210288E-06" iyy="0.000619972366792605" iyz="1.8838609651178E-11" izz="0.00133794742632469" />
    </inertial>
    <visual>
      <origin xyz="0 0 0" rpy="0 0 0" />
      <geometry>
        <mesh filename="package://Wheel_Robot_Sim/meshes/base_link.STL" />
      </geometry>
      <material name="">
        <color rgba="1 1 1 1" />
      </material>
    </visual>
    <collision>
      <origin xyz="0 0 0" rpy="0 0 0" />
      <geometry>
        <mesh filename="package://Wheel_Robot_Sim/meshes/base_link.STL" />
      </geometry>
    </collision>
  </link>
  <link name="laser_link">
    <inertial>
      <origin xyz="-0.0107217166215118 1.18460811424956E-06 0.0107261325903867" rpy="0 0 0" />
      <mass value="0.0865823488601551" />
      <inertia ixx="2.64898105004389E-05" ixy="2.35953372237587E-09" ixz="2.66456504977664E-06" iyy="4.01890246867624E-05" iyz="7.39951577271416E-10" izz="5.75066929524224E-05" />
    </inertial>
    <visual>
      <origin xyz="0 0 0" rpy="0 0 0" />
      <geometry>
        <mesh filename="package://Wheel_Robot_Sim/meshes/laser_link.STL" />
      </geometry>
      <material name="">
        <color rgba="0.796078431372549 0.823529411764706 0.937254901960784 1" />
      </material>
    </visual>
    <collision>
      <origin xyz="0 0 0" rpy="0 0 0" />
      <geometry>
        <mesh filename="package://Wheel_Robot_Sim/meshes/laser_link.STL" />
      </geometry>
    </collision>
  </link>
  <joint name="laser_joint" type="continuous">
    <origin xyz="-0.000500000000000105 0 0.124626149791491" rpy="0 0 0" />
    <parent link="base_link" />
    <child link="laser_link" />
    <axis xyz="0 0 1" />
  </joint>
  <link name="imu_link">
    <inertial>
      <origin xyz="0.00166642390258558 7.06736775417629E-18 0.0010745454413099" rpy="0 0 0" />
      <mass value="0.00215686283305885" />
      <inertia ixx="1.32471275852853E-07" ixy="-8.85725337338877E-23" ixz="-5.8335032681901E-09" iyy="2.97972630345502E-07" iyz="2.36210781708205E-24" izz="4.27056112920458E-07" />
    </inertial>
    <visual>
      <origin xyz="0 0 0" rpy="0 0 0" />
      <geometry>
        <mesh filename="package://Wheel_Robot_Sim/meshes/imu_link.STL" />
      </geometry>
      <material name="">
        <color rgba="0.517647058823529 1 0.384313725490196 1" />
      </material>
    </visual>
    <collision>
      <origin xyz="0 0 0" rpy="0 0 0" />
      <geometry>
        <mesh filename="package://Wheel_Robot_Sim/meshes/imu_link.STL" />
      </geometry>
    </collision>
  </link>
  <joint name="imu_joint" type="fixed">
    <origin xyz="-0.0100000000000001 0 0.094626149791491" rpy="0 0 0" />
    <parent link="base_link" />
    <child link="imu_link" />
    <axis xyz="0 0 0" />
  </joint>
  <link name="left_wheel_link">
    <inertial>
      <origin xyz="-2.30989671834436E-11 0.00928468581982521 -1.50314066749146E-11" rpy="0 0 0" />
      <mass value="0.016863123349881" />
      <inertia ixx="5.00210613971604E-06" ixy="-3.45568268742638E-15" ixz="7.56287498158743E-16" iyy="7.63915210910664E-06" iyz="-1.99682563661997E-15" izz="5.00210614245866E-06" />
    </inertial>
    <visual>
      <origin xyz="0 0 0" rpy="0 0 0" />
      <geometry>
        <mesh filename="package://Wheel_Robot_Sim/meshes/left_wheel_link.STL" />
      </geometry>
      <material name="">
        <color rgba="0.2 0.2 0.2 1" />
      </material>
    </visual>
    <collision>
      <origin xyz="0 0 0" rpy="0 0 0" />
      <geometry>
        <mesh filename="package://Wheel_Robot_Sim/meshes/left_wheel_link.STL" />
      </geometry>
    </collision>
  </link>
  <joint name="left_wheel_joint" type="continuous">
    <origin xyz="0 0.0655 0.0259589732744433" rpy="0 0 0" />
    <parent link="base_link" />
    <child link="left_wheel_link" />
    <axis xyz="0 1 0" />
  </joint>
  <link name="right_wheel_link">
    <inertial>
      <origin xyz="2.67317626367891E-11 -0.0092846858828102 -1.4379178403523E-11" rpy="0 0 0" />
      <mass value="0.0168631232190387" />
      <inertia ixx="5.00210613051693E-06" ixy="-3.69005300943123E-15" ixz="1.05253030042746E-15" iyy="7.63915210593555E-06" iyz="2.36224078811371E-15" izz="5.00210612986154E-06" />
    </inertial>
    <visual>
      <origin xyz="0 0 0" rpy="0 0 0" />
      <geometry>
        <mesh filename="package://Wheel_Robot_Sim/meshes/right_wheel_link.STL" />
      </geometry>
      <material name="">
        <color rgba="0.2 0.2 0.2 1" />
      </material>
    </visual>
    <collision>
      <origin xyz="0 0 0" rpy="0 0 0" />
      <geometry>
        <mesh filename="package://Wheel_Robot_Sim/meshes/right_wheel_link.STL" />
      </geometry>
    </collision>
  </link>
  <joint name="right_wheel_joint" type="continuous">
    <origin xyz="0 -0.0655 0.0259589732744432" rpy="0 0 0" />
    <parent link="base_link" />
    <child link="right_wheel_link" />
    <axis xyz="0 -1 0" />
  </joint>
</robot>

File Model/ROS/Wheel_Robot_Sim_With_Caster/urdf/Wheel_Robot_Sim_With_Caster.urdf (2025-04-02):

<?xml version="1.0" encoding="utf-8"?>
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
<robot name="Wheel_Robot_Sim_With_Caster">
  <link name="base_link">
    <inertial>
      <origin xyz="-0.00238085341264129 2.73544338575261E-09 0.0767638224204377" rpy="0 0 0" />
      <mass value="0.458809382354699" />
      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
    </inertial>
    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
  </link>
  <link name="laser_link">
    <inertial>
      <origin xyz="-0.0107217166215118 1.18460811424954E-06 0.0107261325903867" rpy="0 0 0" />
      <mass value="0.0865823488601551" />
      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
    </inertial>
    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
  </link>
  <joint name="laser_joint" type="continuous">
    <origin xyz="-0.0005 0 0.099266" rpy="0 0 0" />
    <parent link="base_link" />
    <child link="laser_link" />
    <axis xyz="0 0 1" />
  </joint>
  <link name="imu_link">
    <inertial>
      <origin xyz="0.00166642390258558 6.69172556556169E-18 0.0010745454413099" rpy="0 0 0" />
      <mass value="0.00215686283305885" />
      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
    </inertial>
    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
  </link>
  <joint name="imu_joint" type="fixed">
    <origin xyz="-0.01 0 0.069266" rpy="0 0 0" />
    <parent link="base_link" />
    <child link="imu_link" />
    <axis xyz="0 0 0" />
  </joint>
  <link name="left_wheel_link">
    <inertial>
      <origin xyz="-1.69512945347172E-11 0.00928468575182347 -1.4821179006308E-11" rpy="0 0 0" />
      <mass value="0.0168631234860775" />
      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
    </inertial>
    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
  </link>
  <joint name="left_wheel_joint" type="continuous">
    <origin xyz="0 0.0655 0.025959" rpy="0 0 0" />
    <parent link="base_link" />
    <child link="left_wheel_link" />
    <axis xyz="0 1 0" />
  </joint>
  <link name="right_wheel_link">
    <inertial>
      <origin xyz="-1.01945674124693E-11 -0.00928468587360104 -6.90551782422943E-12" rpy="0 0 0" />
      <mass value="0.0168631232301973" />
      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
    </inertial>
    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
  </link>
  <joint name="right_wheel_joint" type="continuous">
    <origin xyz="0 -0.0655 0.025959" rpy="0 0 0" />
    <parent link="base_link" />
    <child link="right_wheel_link" />
    <axis xyz="0 -1 0" />
  </joint>
  <link name="caster_link">
    <inertial>
      <origin xyz="-1.38777878078145E-17 0 6.93889390390723E-18" rpy="0 0 0" />
      <mass value="0.0341934963995502" />
      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
    </inertial>
    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
  </link>
  <joint name="caster_joint" type="fixed">
    <origin xyz="0.0423343035251808 -0.00523961304871963 0.0201307605969319" rpy="0 0 0" />
    <parent link="base_link" />
    <child link="caster_link" />
    <axis xyz="0 0 0" />
  </joint>
</robot>

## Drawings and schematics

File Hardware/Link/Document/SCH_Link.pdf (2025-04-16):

# STM32F1

# Power

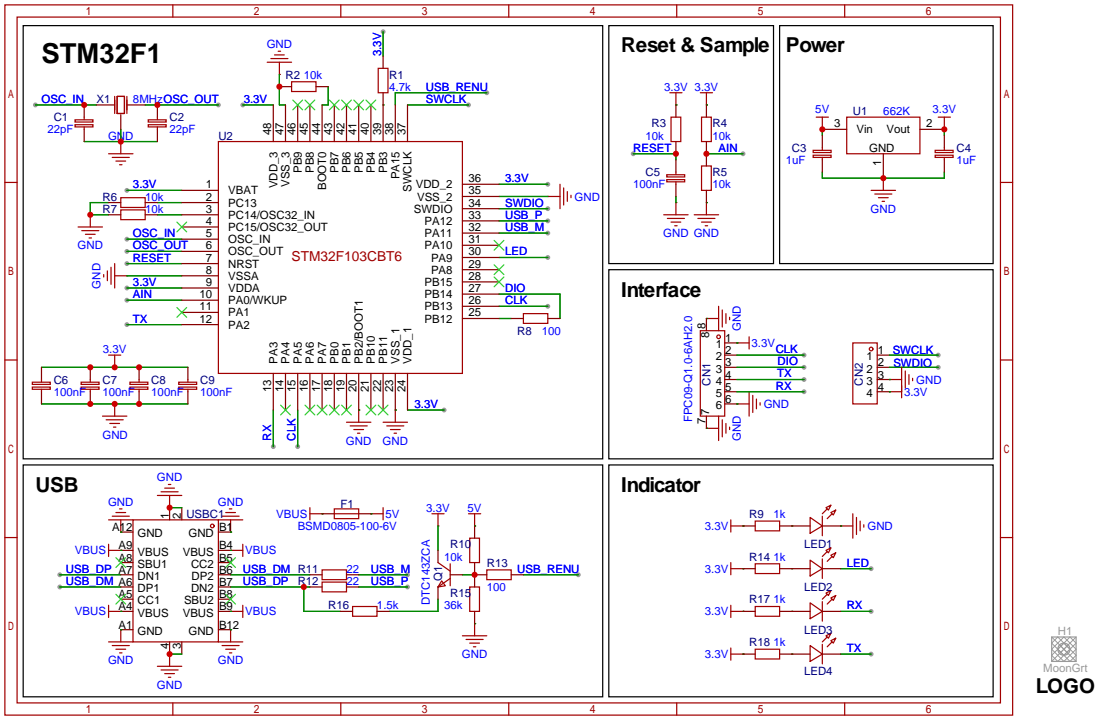
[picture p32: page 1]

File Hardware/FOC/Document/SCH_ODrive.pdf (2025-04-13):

# Minimal System

# Type C

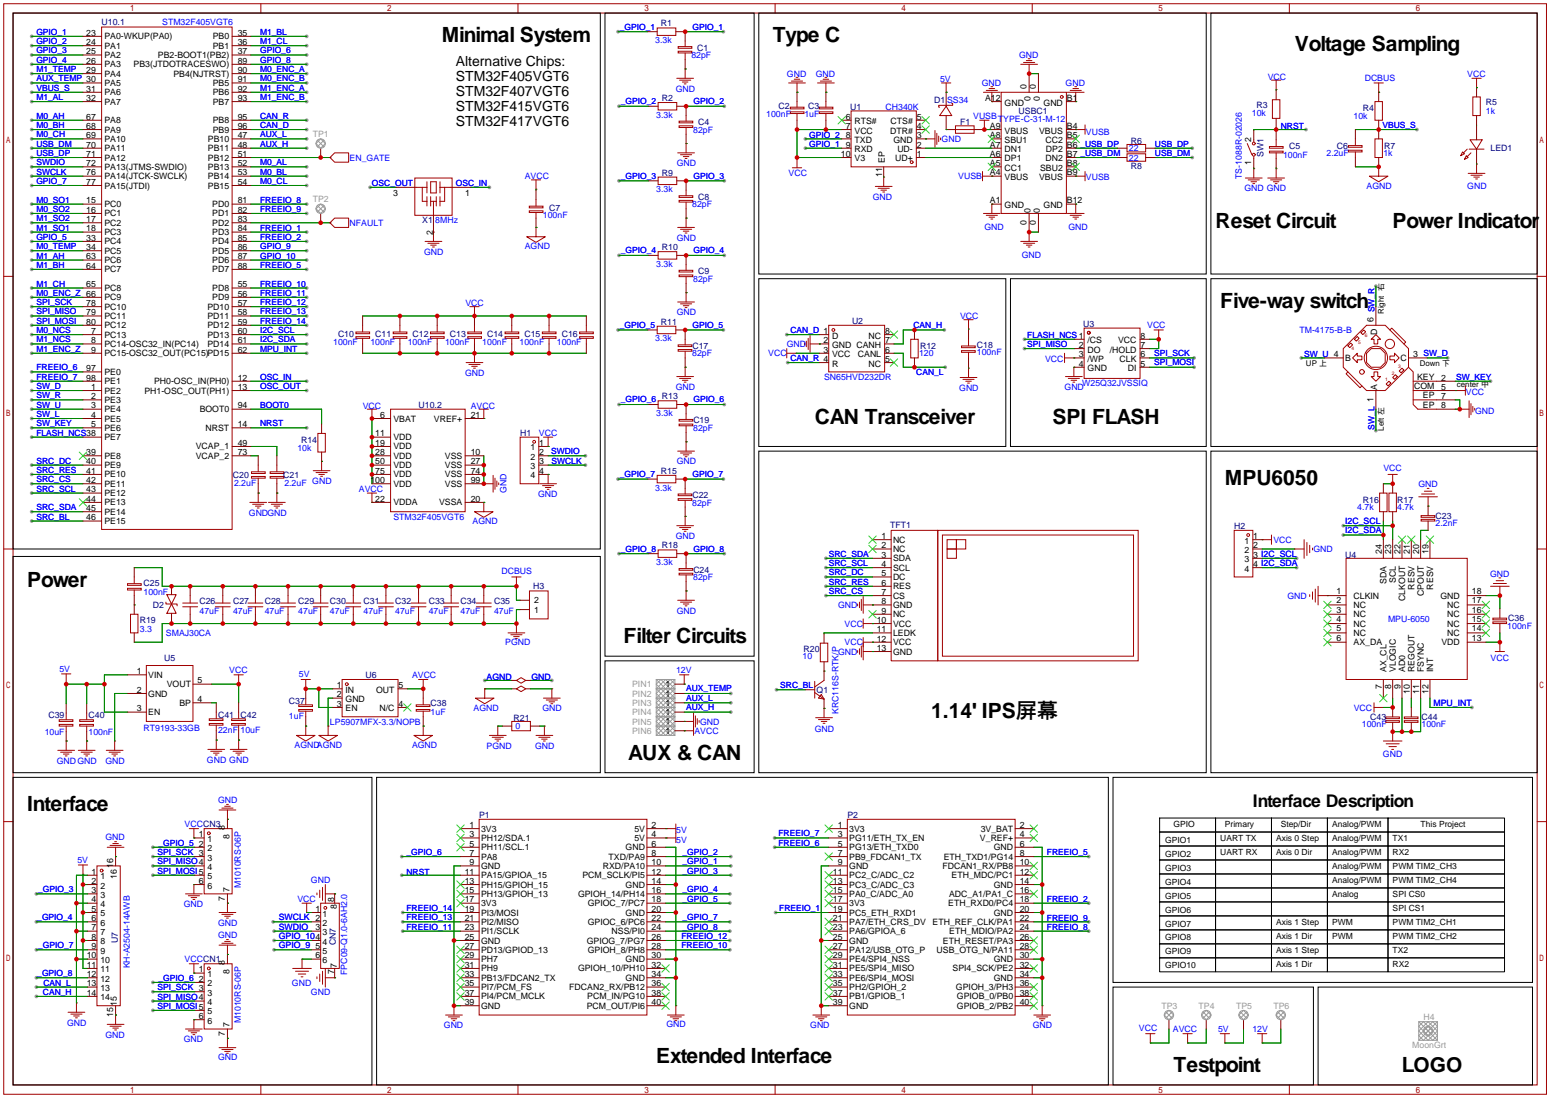
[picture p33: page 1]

RESV 19 CPOUT 20 RESV 21 CLKOUT 22 SCL 23 SDA 24

# GND GND

AGND 28 PVDD1 29 SP2 30 SN2 31 SP1 32 SN1 33 SL-C 34 GL-C 35 SH-C 36 GH-C 37 BST-C 38 SL-B 39 GL-B 40 SH-B 41 GH-B 42 BST-B 43 SL-A 44 GL-A 45 SH-A 46 GH-A 47 BST-A 48 VDD-SPI 49 PH 50 PH 51 BST-BK 52 PVDD2 53 PVDD2 54 EN-BUCK 55 SS-TR 56 EP

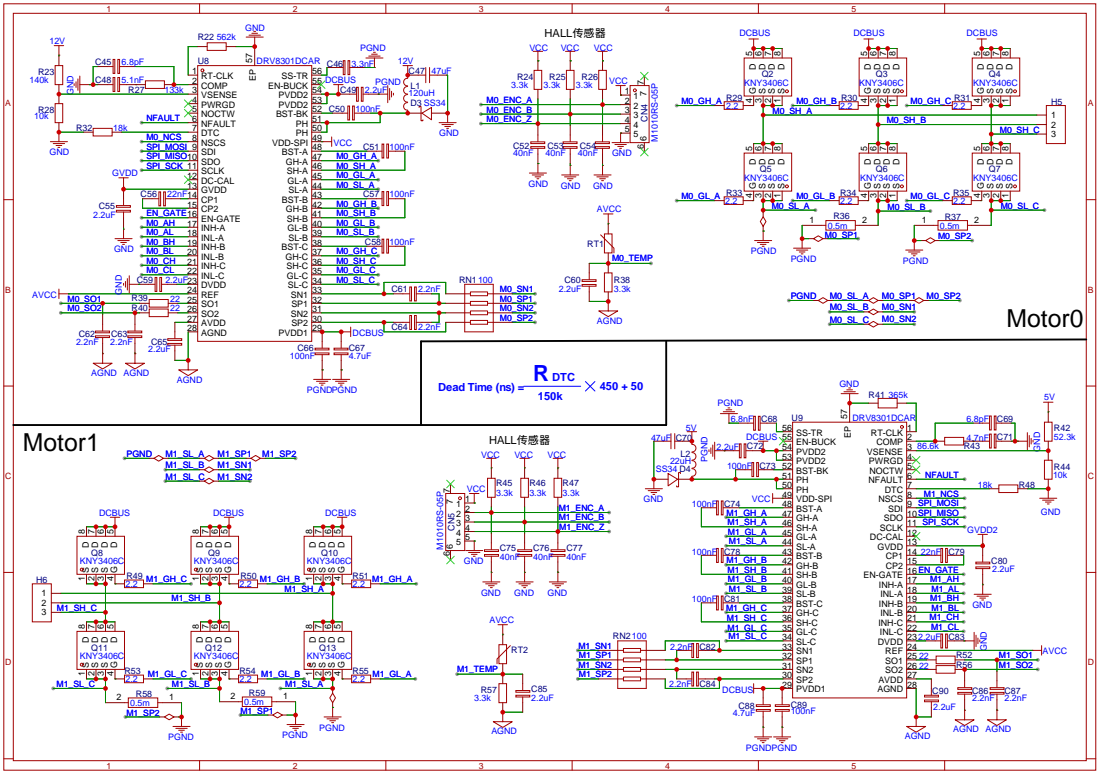
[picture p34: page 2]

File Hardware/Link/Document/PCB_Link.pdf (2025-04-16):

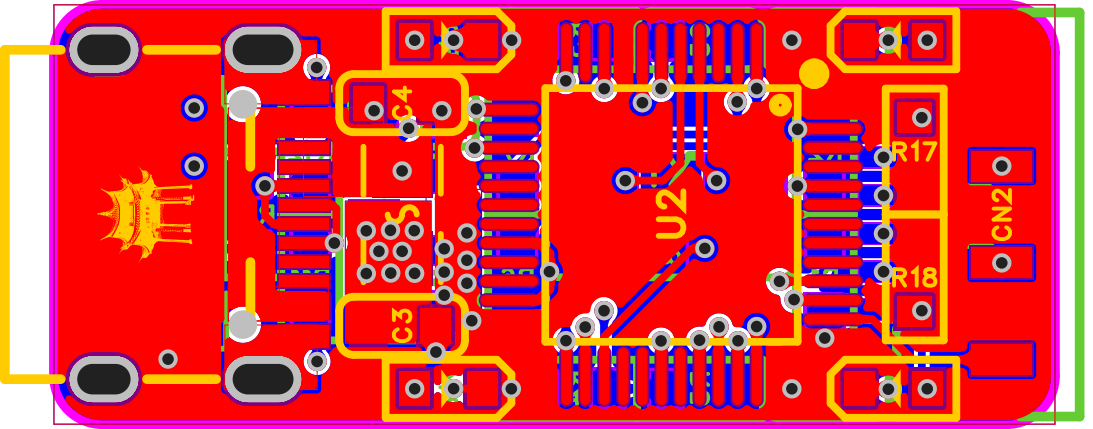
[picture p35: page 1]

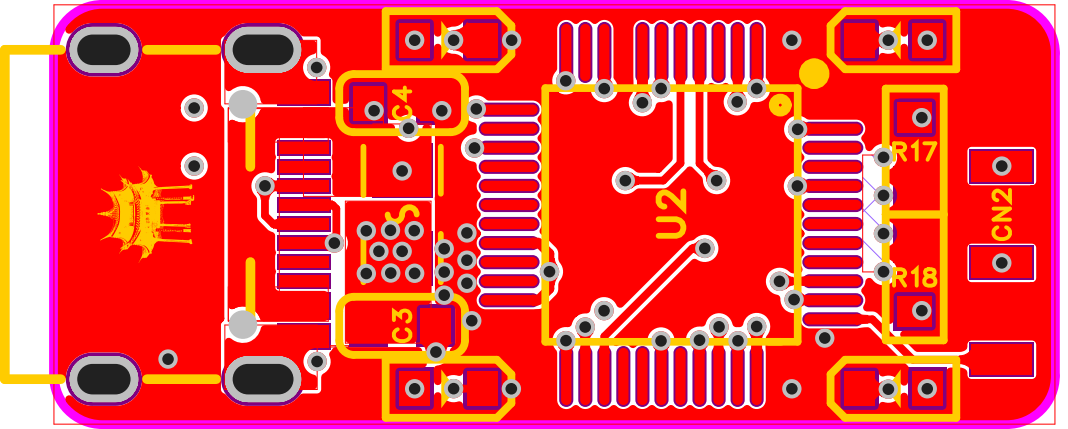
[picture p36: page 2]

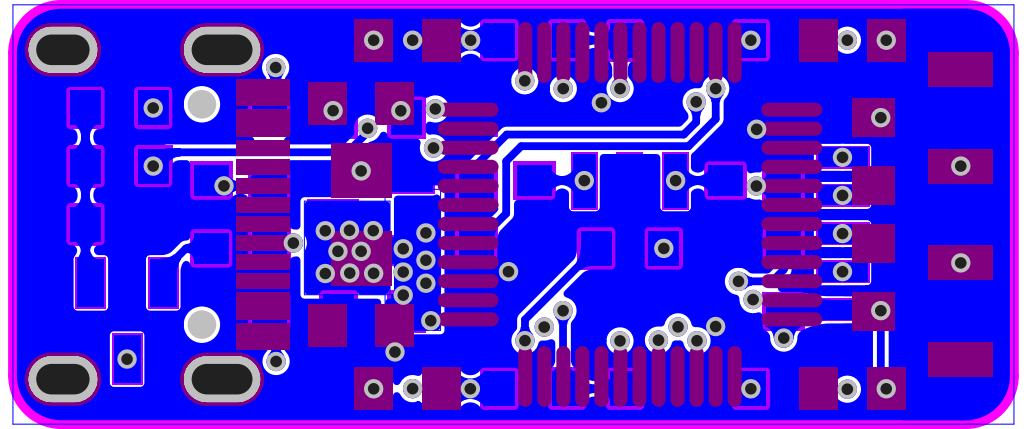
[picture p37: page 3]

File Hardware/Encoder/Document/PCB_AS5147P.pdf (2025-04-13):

CN1

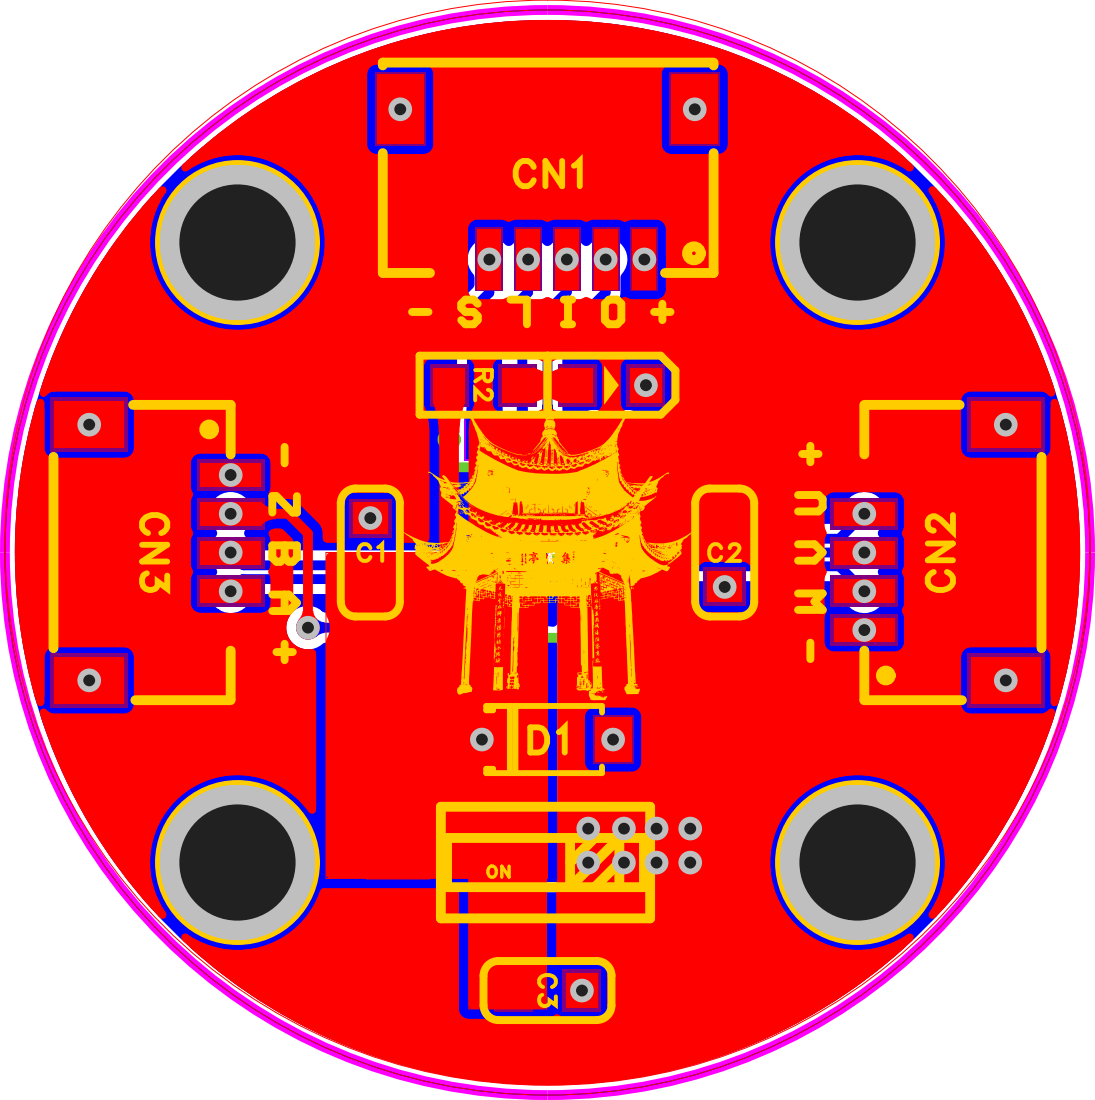
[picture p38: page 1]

CN1

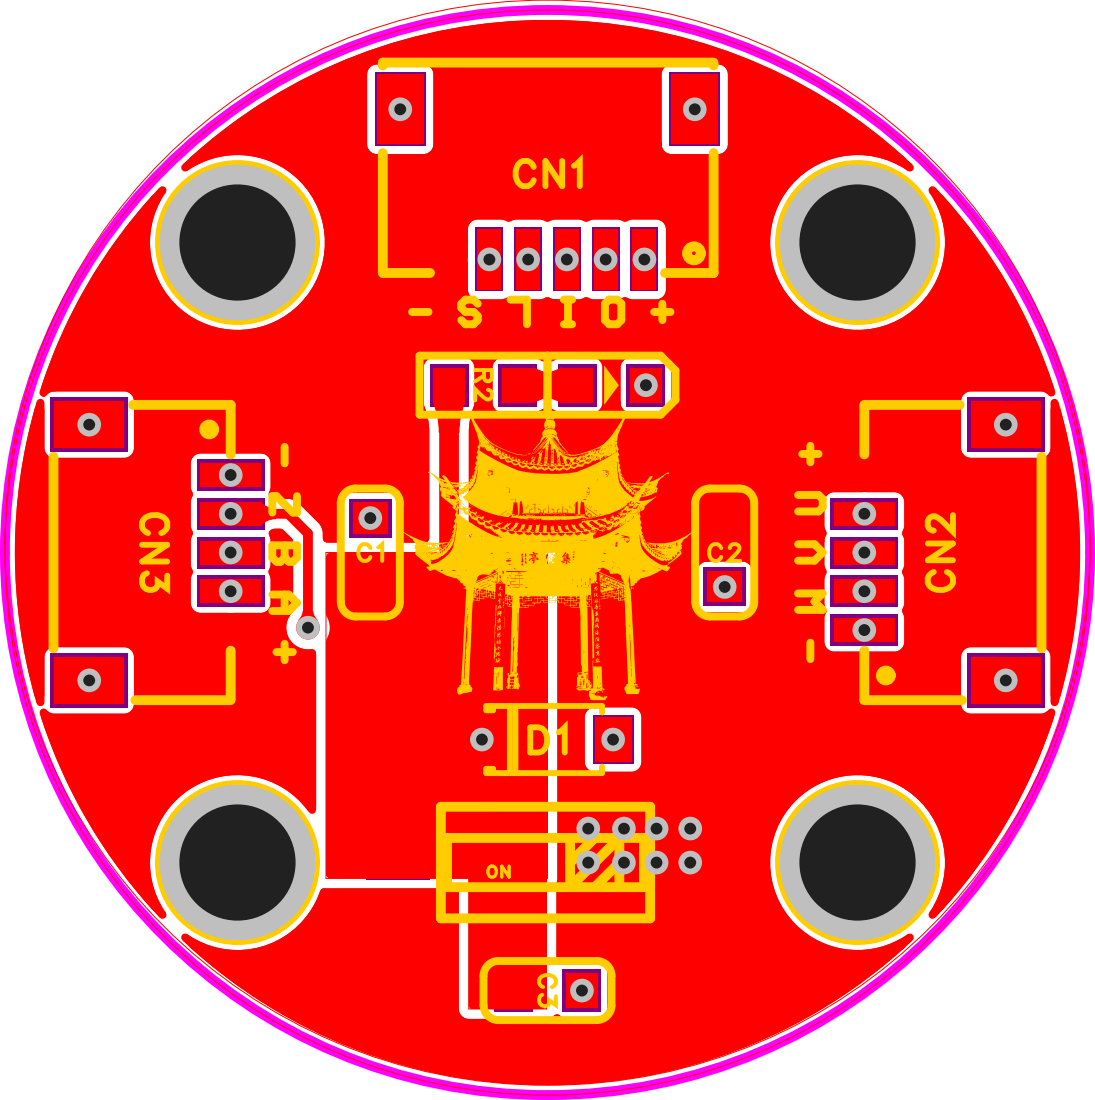
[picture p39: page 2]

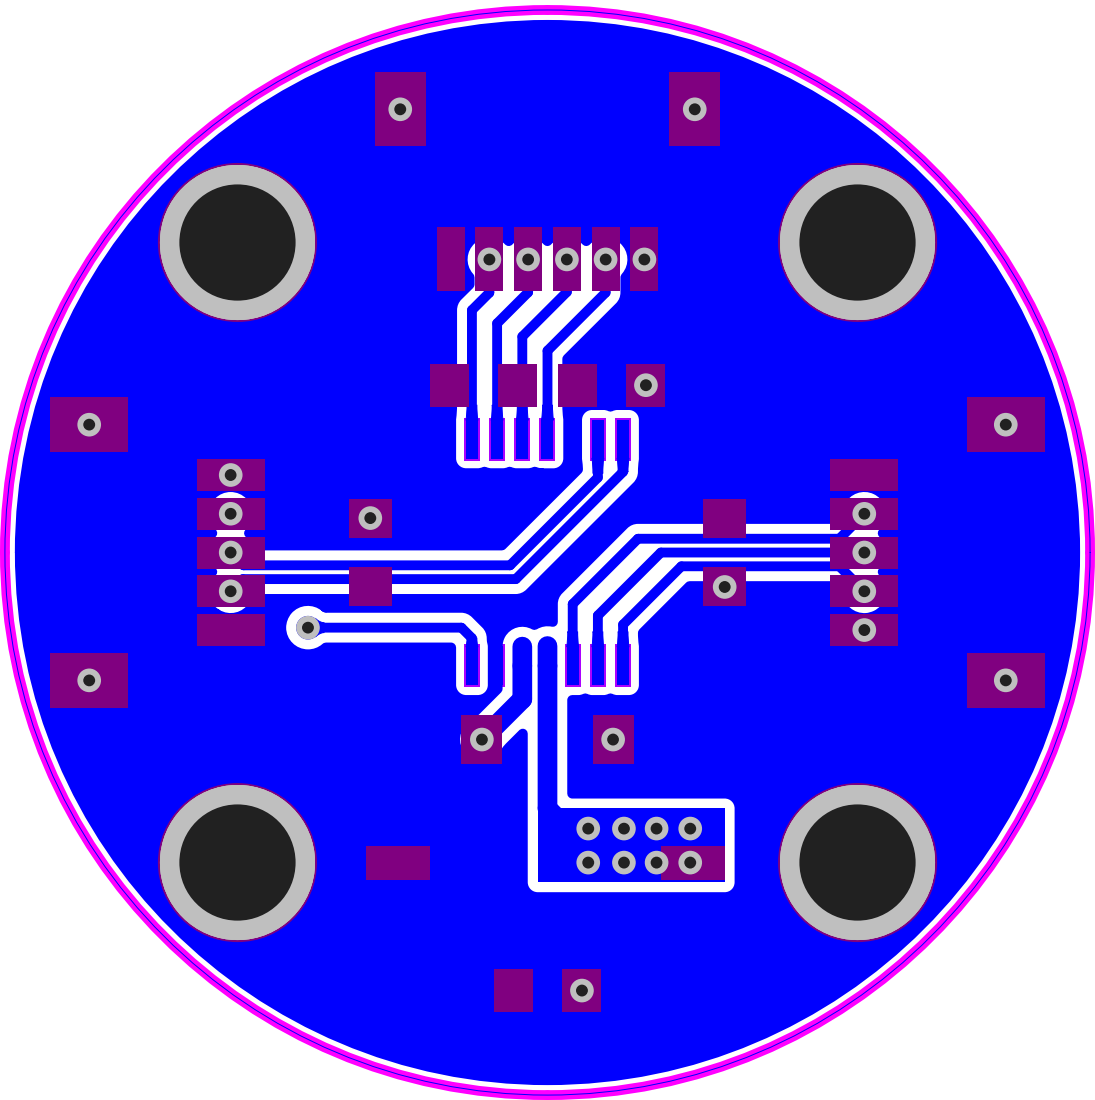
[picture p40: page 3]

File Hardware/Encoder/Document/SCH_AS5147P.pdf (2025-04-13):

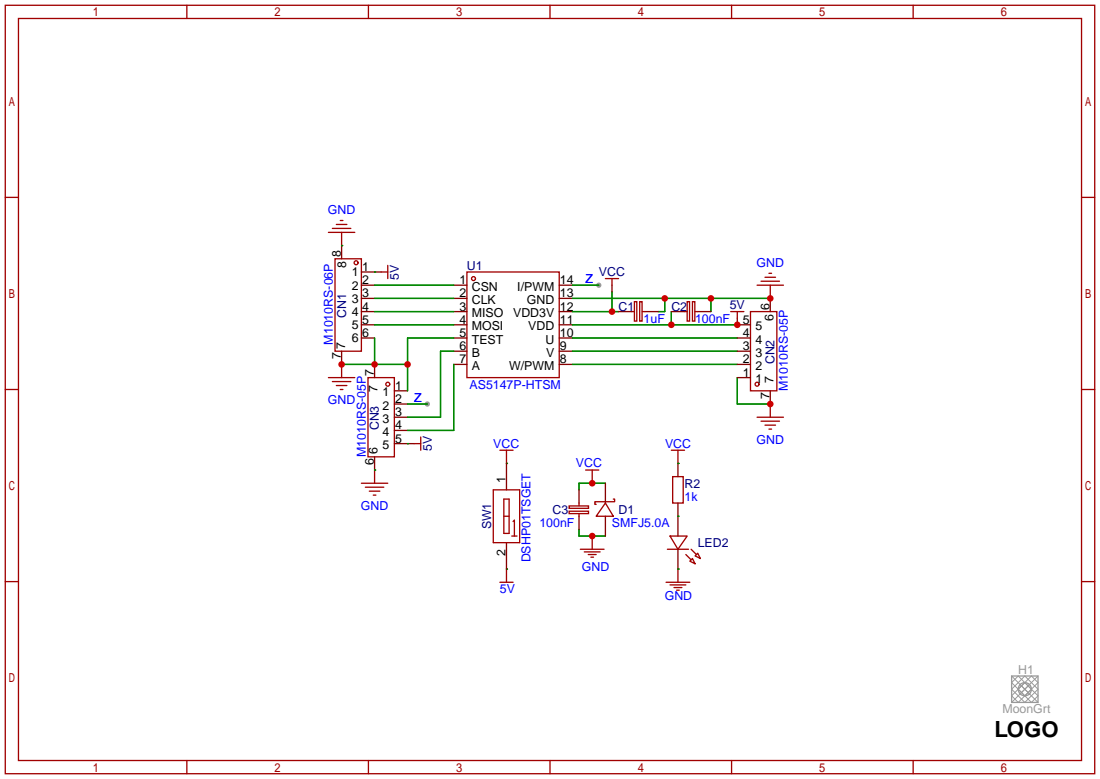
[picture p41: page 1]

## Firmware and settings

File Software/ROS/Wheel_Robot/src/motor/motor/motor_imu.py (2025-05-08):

import rclpy, math, time, threading, sys, serial, struct
import numpy as np
import tf_transformations as tf
from collections import deque
from rclpy.node import Node
from rclpy.time import Time
from tf2_ros import TransformBroadcaster
from nav_msgs.msg import Odometry
from sensor_msgs.msg import JointState, Imu
from geometry_msgs.msg import Twist, Point, Quaternion, TransformStamped
from odrive.enums import *

import matplotlib.pyplot as plt
from matplotlib.backends.backend_qt5agg import FigureCanvasQTAgg as FigureCanvas
from PyQt5.QtWidgets import (
    QWidget, QVBoxLayout, QHBoxLayout, QPushButton,
    QSlider, QLabel, QFrame, QTabWidget, QApplication
)
from PyQt5.QtCore import Qt


class KalmanFilter:
    def __init__(self):
        self.dt = 0.005  # 采样时间
        # 状态变量 [角度, 角速度]
        self.x = np.array([[0], [0]])
        # 状态转移矩阵
        self.A = np.array([[1, -self.dt], [0, 1]])
        # 控制矩阵
        self.B = np.array([[self.dt], [1]])
        # 观测矩阵
        self.H = np.array([[1, 0]])
        # 过程噪声
        self.Q = np.array([[0.001, 0], [0, 0.003]])
        # 观测噪声
        self.R = np.array([[0.03]])
        # 误差协方差
        self.P = np.eye(2)

    def update(self, gyro, accel_angle):
        # 预测步骤
        u = np.array([[gyro]])  # 角速度输入
        x_pred = self.A @ self.x + self.B @ u
        P_pred = self.A @ self.P @ self.A.T + self.Q

        # 观测更新
        z = np.array([[accel_angle]])  # 加速度计计算的角度
        y = z - (self.H @ x_pred)  # 残差
        S = self.H @ P_pred @ self.H.T + self.R
        K = P_pred @ self.H.T @ np.linalg.inv(S)  # 卡尔曼增益

        # 更新状态
        self.x = x_pred + K @ y
        self.P = (np.eye(2) - K @ self.H) @ P_pred

        return self.x[0, 0]  # 返回估计角度


class IMUProcessor:
    def __init__(self):
        self.alpha = 0.97  # 互补滤波系数
        self.roll = 0.0
        self.pitch = 0.0

    def update(self, accel, gyro, dt):
        # 加速度计计算角度（适用于低频、长期稳定）
        # accel_roll = math.atan2(accel[1], accel[2])
        accel_pitch = math.atan2(-accel[0], math.sqrt(accel[1]**2 + accel[2]**2))
        # 陀螺仪积分计算角度（短期稳定，易漂移）
        # gyro_roll = self.roll + gyro[0] * dt
        gyro_pitch = self.pitch + gyro[1] * dt
        # 互补滤波
        # self.roll = self.alpha * gyro_roll + (1 - self.alpha) * accel_roll
        self.pitch = self.alpha * gyro_pitch + (1 - self.alpha) * accel_pitch
        return self.pitch


class MotorIMUNode(Node):
    def __init__(self, motor_port_name, motor_baudrate, imu_port_name, imu_baudrate):
        super().__init__('motor_imu_node')
        self.params_init()
        self.task_init(motor_port_name, motor_baudrate, imu_port_name, imu_baudrate)

    def params_init(self):
        self.motor = None

        # 上次回调时间
        self.last_time_read_motor = time.time()
        self.last_time_pid = time.time()
        self.last_time_imu_callback = time.time()

        # PID参数
        self.speed_kp, self.speed_ki, self.speed_kd = 0.0, 0.0, 0.0
        self.angle_kp, self.angle_ki, self.angle_kd = 10, 0.0, 0.2
        self.angular_kp, self.angular_ki, self.angular_kd = 1, 0.0, 0.0

        # 状态变量
        self.speed_error = 0
        self.angle_error = 0
        self.angular_error = 0
        self.speed_integral = 0
        self.angle_integral = 0
        self.angular_integral = 0
        self.prev_speed_error = 0
        self.prev_angle_error = 0
        self.prev_angular_error = 0

        # 来自轮速传感器的速度估计
        self.motor_pos0 = 0
        self.motor_pos1 = 0
        self.motor_vel0 = 0
        self.motor_vel1 = 0
        self.motor_pos0_filter = 0
        self.motor_pos1_filter = 0
        self.motor_vel0_filter = 0
        self.motor_vel1_filter = 0

        # 目标角度
        self.target_roll = 0
        self.target_pitch = 0
        # 运动参数
        self.target_linear = 0.0
        self.target_angular = 0.0
        # 机器人物理参数
        self.x = 0.0
        self.y = 0.0
        self.wheel_base = 0.174    # 车轮间距 (meters)
        self.wheel_radius = 0.026  # 轮子半径 (meters)

        self.pitch_max = 0.4048
        self.pitch_min = -0.5031
        self.pitch_mid = (self.pitch_max + self.pitch_min) / 2
        self.max_speed = 15.0  # 电机最大转速 (rad/s)
        self.max_angle = 90.0
        self.min_angle = 0.0

        # calibration
        self.max_samples = 100  # calibate 时采样 100 次
        self.pitch_sum = 0
        self.sample_count = 0
        self.calibration_complete = True

    def task_init(self, motor_port_name, motor_baudrate, imu_port_name, imu_baudrate):
        self.motor_run = False
        self.imu_processor = IMUProcessor()
        self.kf_pitch = KalmanFilter()

        # 初始化订阅
        self.cmd_vel_sub = self.create_subscription(Twist, 'cmd_vel', self.cmd_vel_callback, 10)

        # 创建 IMU Publisher
        self.imu_msg = Imu()
        self.imu_msg.header.frame_id = 'imu_link'
        self.imu_pub = self.create_publisher(Imu, 'imu', 10)

        # 启动 Motor 驱动线程
        self.motor_thread_running = True
        self.serial_lock = threading.Lock()
        self.motor_thread = threading.Thread(target=self.motor_thread_loop, args=(motor_port_name, motor_baudrate, ), daemon=True)
        self.motor_thread.start()

        # 创建 Odometry Publisher
        self.odom_frame_id = 'odom'
        self.child_frame_id = 'base_link'
        self.odom_tf = TransformBroadcaster(self)
        self.odom_pub = self.create_publisher(Odometry, 'odom', 10)
        self.joint_pub = self.create_publisher(JointState, 'joint_states', 10)

        # 启动 IMU 驱动线程
        self.accel = [0.0, 0.0, 0.0]
        self.gyro = [0.0, 0.0, 0.0]
        self.angle = [0.0, 0.0, 0.0]
        self.pitch = 0
        self.imu_key = 0
        self.imu_falg = 0
        self.imu_buff = {}
        self.IMU_thread_running = True
        self.IMU_thread = threading.Thread(target=self.imu_thread_loop, args=(imu_port_name, imu_baudrate, ), daemon=True)
        self.IMU_thread.start()

        # 数据记录
        self.plot_num = 200
        self.speed_error_data = deque([0.0]*self.plot_num, maxlen=self.plot_num)
        self.speed_output_data = deque([0.0]*self.plot_num, maxlen=self.plot_num)
        self.angle_error_data = deque([0.0]*self.plot_num, maxlen=self.plot_num)
        self.angle_output_data = deque([0.0]*self.plot_num, maxlen=self.plot_num)
        self.angular_error_data = deque([0.0]*self.plot_num, maxlen=self.plot_num)
        self.angular_output_data = deque([0.0]*self.plot_num, maxlen=self.plot_num)
        self.data1 = deque([0.0]*self.plot_num, maxlen=self.plot_num)
        self.data2 = deque([0.0]*self.plot_num, maxlen=self.plot_num)
        self.data3 = deque([0.0]*self.plot_num, maxlen=self.plot_num)
        self.data4 = deque([0.0]*self.plot_num, maxlen=self.plot_num)

    def cmd_vel_callback(self, msg:Twist):
        self.target_linear = msg.linear.x
        self.target_angular = msg.angular.z
        # self.get_logger().info(f"收到指令: 线速度={self.target_linear}m/s, 角速度={self.target_angular}rad/s")

    def publish_thread_loop(self):
        while self.publish_thread_running and self.motor:
            current_time = time.time()
            dt = max(current_time - self.last_time_read_motor, 1e-6)  # 防止除以0
            self.last_time_read_motor = current_time
            # print(f'dt: {dt:.5f}, pos0: {self.motor_pos0:.5f}, vel0: {self.motor_vel0:.5f}')

            self.read_motor()
            self.publish_msg()

    def imu_thread_loop(self, port_name, baudrate):
        # 打开串口
        try:
            self.imu = serial.Serial(port=port_name, baudrate=baudrate, timeout=0.5)
            if self.imu.isOpen():
                self.get_logger().info("\033[32mIMU serial port connection establised...\033[0m")
                self.get_logger().info("\033[32mIMU Node started...\033[0m")
            else:
                self.imu.open()
                self.get_logger().info("\033[32mSerial port opened successfully...\033[0m")
        except Exception as e:
            self.get_logger().error(str(e))
            self.get_logger().info("\033[31mMotor serial port opening failure\033[0m")

        # 循环读取IMU数据
        while self.IMU_thread_running and self.imu:
            # 读取加速度计数据
            try:
                buff_count = self.imu.inWaiting()
            except Exception as e:
                print("exception:" + str(e))
                print("imu disconnect")
            else:
                if buff_count > 0:
                    buff_data = self.imu.read(buff_count)
                    for i in range(0, buff_count):
                        tag = self.handle_serial_data(buff_data[i])
                        if tag:
                            self.imu_data()
                if not self.calibration_complete:
                    if self.sample_count == 0:
                        self.motor_send_cmd(f'w axis0.requested_state {AxisState.IDLE}')
                        self.motor_send_cmd(f'w axis1.requested_state {AxisState.IDLE}')
                        print('IDLE')
                    elif self.sample_count == self.max_samples:
                        self.motor_send_cmd(f'w axis0.requested_state {AxisState.CLOSED_LOOP_CONTROL}')
                        self.motor_send_cmd(f'w axis1.requested_state {AxisState.CLOSED_LOOP_CONTROL}')
                        print('LOOP')
                    if self.sample_count < self.max_samples:
                        if self.sample_count == 0:
                            print("校准中... 请保持平衡车在平衡状态，正在采样...")
                        self.sample_count += 1
                        self.pitch_sum += self.pitch
                        print(f'pitch: {self.pitch:.5f}')
                    else:
                        self.target_pitch = (self.pitch_sum / self.max_samples)
                        print(f"校准完成，目标平衡角度：{self.target_pitch:.5f}")
                        self.calibration_complete = True
                        self.sample_count = 0
                        self.pitch_sum = 0

    def motor_thread_loop(self, port_name, baudrate):
        # 连接 Motor
        try:
            self.motor = serial.Serial(port=port_name, baudrate=baudrate, timeout=0.1)
            self.set_servo_angle(25, 25)
            self.get_logger().info("\033[32mMotor serial port connection established...\033[0m")
            self.motor_setup()
            self.get_logger().info("\033[32mMotor Setup Successed...\033[0m")
        except Exception as e:
            self.get_logger().error(str(e))
            self.get_logger().info("\033[31mIMU serial port opening failure\033[0m")
            if self.motor:
                self.motor.close()
            return

        # Publish thread
        self.publish_thread_running = True
        self.publish_thread = threading.Thread(target=self.publish_thread_loop, daemon=True)
        self.publish_thread.start()

        time.sleep(1.5)
        while self.motor_thread_running and self.motor:
            current_time = time.time()
            dt = max(current_time - self.last_time_pid, 1e-6)  # 防止除以0
            self.last_time_pid = current_time

            left_speed, right_speed = self.cascaded_pid_control(dt)
            print(f'dt: {dt:.5f}, pitch: {round(self.pitch, 3)}, error: {self.angle_error:.5f}')
            # print(f'ls: {left_speed:.4f}, rs: {right_speed:.4f}')
            if not self.motor_run or not self.calibration_complete or abs(self.angle_error) > 0.30:
                self.motor.write('v 0 0.0\nv 1 0.0\n'.encode())
            else:
                self.set_motor_speeds(left_speed, right_speed, direction=1)
            time.sleep(0.005)

    def cascaded_pid_control(self, dt):
        # self.motor_vel0_filter = 0.3 * self.motor_vel0 + 0.7 * self.motor_vel0_filter
        # self.motor_vel1_filter = 0.3 * self.motor_vel1 + 0.7 * self.motor_vel1_filter
        # left_speed = self.motor_vel0_filter
        # right_speed = self.motor_vel1_filter
        left_speed = self.motor_vel0
        right_speed = self.motor_vel1

        # self.data1.append(self.motor_pos0)
        self.data2.append(right_speed)

        # 当前车速(机器人线速度)：左右轮速度平均 (未转换为车轮实际线速度)
        current_linear_speed = (self.motor_vel0 + self.motor_vel1) / 2.0
        current_angular_speed = (self.motor_vel1 - self.motor_vel0) / self.wheel_base

        # self.gyro_y_filter = 0.3 * self.gyro[1] + 0.7 * self.gyro_y_filter  # TODO

        # ========== 1. 速度环 PID ==========
        self.speed_error = current_linear_speed - self.target_linear  # 当前速度可由轮速传感器提供
        self.speed_integral += self.speed_error * dt
        speed_derivative = ((self.speed_error - self.prev_speed_error) / dt)
        speed_output = (
            self.speed_kp * self.speed_error +
            self.speed_ki * self.speed_integral +
            self.speed_kd * speed_derivative
        )
        self.prev_speed_error = self.speed_error
        desired_pitch = self.target_pitch + speed_output  # 外环输出为期望角度

        # ========== 2. 角度环 PID ==========
        self.angle_error = round(self.pitch, 3) - desired_pitch
        self.angle_integral += self.angle_error * dt
        angle_derivative = ((self.angle_error - self.prev_angle_error) / dt)
        angle_output = (
            self.angle_kp * self.angle_error +
            self.angle_ki * self.angle_integral +
            self.angle_kd * angle_derivative
        )
        self.prev_angle_error = self.angle_error
        desired_angular_velocity = angle_output  # 输出为期望角速度

        # ========== 3. 角速度环 PID ==========
        self.angular_error = 0 - desired_angular_velocity
        self.angular_integral += self.angular_error * dt
        angular_derivative = ((self.angular_error - self.prev_angular_error) / dt)
        angular_output = (
            self.angular_kp * self.angular_error +
            self.angular_ki * self.angular_integral +
            self.angular_kd * angular_derivative
        )
        self.prev_angular_error = self.angular_error

        # ========== 电机速度合成 ==========
        linear_speed = self.target_linear  # 线速度: 未转换为车轮目标线速度
        angular_diff = (self.target_angular * self.wheel_base) / 2  # 角速度差分: 未转换为车轮目标线速度
        left_speed = (linear_speed - angular_diff) - angular_output
        right_speed = (linear_speed + angular_diff) + angular_output

        # 记录日志
        self.speed_error_data.append(self.speed_error)
        self.speed_output_data.append(speed_output)
        self.angle_error_data.append(self.angle_error)
        self.angle_output_data.append(angle_output)
        self.angular_error_data.append(self.angular_error)
        self.angular_output_data.append(angular_output)
        self.data1.append(angle_output)

        return left_speed, right_speed

    def motor_setup(self):
        while (True):
            # 切换到闭环控制
            self.motor_send_cmd(f'w axis0.requested_state {AxisState.CLOSED_LOOP_CONTROL}')
            self.motor_send_cmd(f'w axis1.requested_state {AxisState.CLOSED_LOOP_CONTROL}')
            errors = self.check_motor_error()
            if errors:
                self.handle_motor_error(errors)
                # 等待错误处理完成
                while True:
                    state0 = int(self.motor_send_cmd('r axis0.current_state'))
                    state1 = int(self.motor_send_cmd('r axis1.current_state'))
                    if state0 == AxisState.IDLE and state1 == AxisState.IDLE:
                        break
                    time.sleep(0.1)
            else:
                # self.motor_send_cmd(f'w axis0.requested_state {AxisState.IDLE}')
                # self.motor_send_cmd(f'w axis1.requested_state {AxisState.IDLE}')
                break

    def motor_send_cmd(self, cmd:str):
        # 在写操作前后上锁
        with self.serial_lock:
            # 底层写串口
            if self.motor:
                try:
                    self.motor.write((cmd + '\n').encode())
                    return self.motor.readline().decode().strip()
                except Exception as e:
                    print(f'motor cmd send failed {e}')

    def motor_loop(self):
        self.motor_send_cmd(f'w axis0.requested_state {AxisState.CLOSED_LOOP_CONTROL}')
        self.motor_send_cmd(f'w axis1.requested_state {AxisState.CLOSED_LOOP_CONTROL}')
        self.motor_send_cmd('v 0 0.0 0.0')
        self.motor_send_cmd('v 1 0.0 0.0')

    def motor_idle(self):
        self.motor_send_cmd(f'w axis0.requested_state {AxisState.IDLE}')
        self.motor_send_cmd(f'w axis1.requested_state {AxisState.IDLE}')
        self.motor_send_cmd('v 0 0.0 0.0')
        self.motor_send_cmd('v 1 0.0 0.0')

    def check_motor_error(self, clear=True, full=True):
        errors = []

        # ANSI颜色代码
        RED = "\033[91m"
        YELLOW = "\033[93m"
        RESET = "\033[0m"

        def decode_flags(val, enum_type):
            val = int(val, 0)
            msgs = []
            for bit in range(64):
                flag = 1 << bit
                if val & flag:
                    try:
                        name = enum_type(flag).name
                        msgs.append(f"{enum_type.__name__}.{name}")
                    except ValueError:
                        msgs.append(f"Unknown: 0x{flag:08X}")
            return msgs

        def check_path_error(indent, name, obj, path, enum_type):
            val = self.motor_send_cmd(f"r {path}")
            if val == '':
                return
            decoded = decode_flags(val, enum_type)

            show = full or bool(decoded)
            if show:
                color = RED if decoded else RESET
                print(f"{indent}{color}{obj} = {val}{RESET}")
                for msg in decoded:
                    print(f"{indent}  {YELLOW}⮡ {msg}{RESET}")

            if decoded:
                errors.append({
                    "name": name,
                    "obj": obj,
                    "path": path,
                    "type": enum_type,
                    "raw": val,
                    "decoded": decoded
                })

        check_path_error("", "system", "system.error", "error", LegacyODriveError)

        for axis in [0, 1]:
            name = f"axis{axis}"
            print(f"{name}:")
            check_path_error("  ", name, "axis.error", f"{name}.error", AxisError)
            check_path_error("  ", name, "motor.error", f"{name}.motor.error", MotorError)
            check_path_error("  ", name, "encoder.error", f"{name}.encoder.error", EncoderError)
            check_path_error("  ", name, "controller.error", f"{name}.controller.error", ControllerError)

        if clear:
            self.motor_send_cmd("sc")

        return errors

    def handle_motor_error(self, errors):
        for err in errors:
            name = err["name"]
            obj = err["obj"]
            type = err["type"]
            raw = err["raw"]
            decoded = err["decoded"]

            # 根据错误代码执行相应的错误处理函数
            if type == AxisError:
                pass
            elif type == MotorError:
                for code in decoded:
                    # 示例：根据错误类型分类处理
                    if "DRV_FAULT" in code:
                        self.motor_send_cmd('sc')
                    elif "OVER_TEMP" in code:
                        pass
                    elif "UNKNOWN_PHASE_ESTIMATE" in code:
                        self.motor_calibration(name)
            elif type == EncoderError:
                self.motor_calibration(name)
            elif type == ControllerError:
                pass

    def motor_calibration(self, name):
        # 启动编码器偏移校准
        if name == 'system':
            return
        self.motor_send_cmd(f'w {name}.requested_state {AxisState.ENCODER_OFFSET_CALIBRATION}')

    def read_motor(self):
        # 读取数据
        try:
            pos = self.motor_send_cmd('r p')
            vel = self.motor_send_cmd('r v')
            if pos and vel:
                self.motor_pos0, self.motor_pos1 = map(float, pos.split())
                self.motor_vel0, self.motor_vel1 = map(float, vel.split())
                # print(f"pos0={-self.motor_pos0}, vel0={-self.motor_vel0}, pos1={self.motor_pos1}, vel1={self.motor_vel1}")
        except ValueError:
            print('Invalid data format')

    def publish_msg(self):
        # 计算机器人位置和姿态
        # 计算左右轮的线速度
        v_left = (-self.motor_vel0) * self.wheel_radius
        v_right = self.motor_vel1 * self.wheel_radius
        # 线速度和角速度
        linear_velocity = (v_left + v_right) / 2.0
        angular_velocity = (v_right - v_left) / self.wheel_base

        # 更新机器人的位置
        # 计算左右轮的线性行驶距离
        d_left = (-self.motor_pos0) * 2 * math.pi * self.wheel_radius
        d_right = self.motor_pos1 * 2 * math.pi * self.wheel_radius
        # 计算机器人行驶的距离和角度变化
        d = (d_left + d_right) / 2.0
        self.theta = (d_right - d_left) / self.wheel_base
        # 直接使用 pos0 和 pos1 计算位置
        self.x = d * math.cos(self.theta)
        self.y = d * math.sin(self.theta)

        # 发布TransformStamped消息
        odom_trans = TransformStamped()
        odom_trans.header.stamp = self.get_clock().now().to_msg()
        odom_trans.header.frame_id = self.odom_frame_id
        odom_trans.child_frame_id = self.child_frame_id
        # 设置位置和姿态
        odom_trans.transform.translation.x = self.x
        odom_trans.transform.translation.y = self.y
        odom_trans.transform.rotation.w = math.cos(self.theta / 2)
        odom_trans.transform.rotation.z = math.sin(self.theta / 2)
        self.odom_tf.sendTransform(odom_trans)

        # 创建Odometry消息
        odom_msg = Odometry()
        odom_msg.header.stamp = self.get_clock().now().to_msg()
        odom_msg.header.frame_id = self.odom_frame_id
        odom_msg.child_frame_id = self.child_frame_id
        # 设置位置和姿态
        odom_msg.pose.pose.position = Point(x=self.x, y=self.y, z=0.0)
        odom_msg.pose.pose.orientation = Quaternion(
            x=0.0, y=0.0, z=math.sin(self.theta / 2), w=math.cos(self.theta / 2)
        )
        odom_msg.twist.twist.linear.x = linear_velocity
        odom_msg.twist.twist.angular.z = angular_velocity
        self.odom_pub.publish(odom_msg)
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

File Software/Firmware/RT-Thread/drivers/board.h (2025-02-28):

/*
 * Copyright (c) 2006-2025, RT-Thread Development Team
 *
 * SPDX-License-Identifier: Apache-2.0
 *
 * Change Logs:
 * Date           Author       Notes
 * 2025-02-15     RealThread   first version
 */

#ifndef __BOARD_H__
#define __BOARD_H__

#include <stm32f4xx.h>
#include <drv_common.h>


#ifdef __cplusplus
extern "C"
{
#endif

/*-------------------------- CHIP CONFIG BEGIN --------------------------*/

#define CHIP_FAMILY_STM32
#define CHIP_SERIES_STM32F4
#define CHIP_NAME_STM32F405VG

/*-------------------------- CHIP CONFIG END --------------------------*/

/*-------------------------- ROM/RAM CONFIG BEGIN --------------------------*/

#define ROM_START              ((uint32_t)0x08000000)
#define ROM_SIZE               (1024 * 1024)
#define ROM_END                ((uint32_t)(ROM_START + ROM_SIZE))

#define RAM_START              (0x20000000)
#define RAM_SIZE               (128 * 1024)
#define RAM_END                (RAM_START + RAM_SIZE)

/*-------------------------- ROM/RAM CONFIG END --------------------------*/

/*-------------------------- CLOCK CONFIG BEGIN --------------------------*/

#define BSP_CLOCK_SOURCE                  ("HSI")
#define BSP_CLOCK_SOURCE_FREQ_MHZ         ((int32_t)0)
#define BSP_CLOCK_SYSTEM_FREQ_MHZ         ((int32_t)168)

/*-------------------------- CLOCK CONFIG END --------------------------*/

/*-------------------------- UART CONFIG BEGIN --------------------------*/

/** After configuring corresponding UART or UART DMA, you can use it.
 *
 * STEP 1, define macro define related to the serial port opening based on the serial port number
 *                 such as     #define BSP_USING_UART1
 *
 * STEP 2, according to the corresponding pin of serial port, define the related serial port information macro
 *                 such as     #define BSP_UART1_TX_PIN       "PA9"
 *                             #define BSP_UART1_RX_PIN       "PA10"
 *
 * STEP 3, if you want using SERIAL DMA, you must open it in the RT-Thread Settings.
 *                 RT-Thread Setting -> Components -> Device Drivers -> Serial Device Drivers -> Enable Serial DMA Mode
 *
 * STEP 4, according to serial port number to define serial port tx/rx DMA function in the board.h file
 *                 such as     #define BSP_UART1_RX_USING_DMA
 *
 */

#define BSP_USING_UART4
#define BSP_UART4_TX_PIN       "PA0"
#define BSP_UART4_RX_PIN       "PA1"

/*-------------------------- UART CONFIG END --------------------------*/

/*-------------------------- I2C CONFIG BEGIN --------------------------*/

/** if you want to use i2c bus(soft simulate) you can use the following instructions.
 *
 * STEP 1, open i2c driver framework(soft simulate) support in the RT-Thread Settings file
 *
 * STEP 2, define macro related to the i2c bus
 *                 such as     #define BSP_USING_I2C1
 *
 * STEP 3, according to the corresponding pin of i2c port, modify the related i2c port and pin information
 *                 such as     #define BSP_I2C1_SCL_PIN    GET_PIN(port, pin)   ->   GET_PIN(C, 11)
 *                             #define BSP_I2C1_SDA_PIN    GET_PIN(port, pin)   ->   GET_PIN(C, 12)
 */

#define BSP_USING_I2C1

/*#define BSP_USING_I2C1*/
#ifdef BSP_USING_I2C1
#define BSP_I2C1_SCL_PIN    GET_PIN(D, 13)
#define BSP_I2C1_SDA_PIN    GET_PIN(D, 14)
#endif

/*#define BSP_USING_I2C2*/
#ifdef BSP_USING_I2C2
#define BSP_I2C2_SCL_PIN    GET_PIN(port, pin)
#define BSP_I2C2_SDA_PIN    GET_PIN(port, pin)
#endif

/*-------------------------- I2C CONFIG END --------------------------*/

/*-------------------------- SPI CONFIG BEGIN --------------------------*/

/** if you want to use spi bus you can use the following instructions.
 *
 * STEP 1, open spi driver framework support in the RT-Thread Settings file
 *
 * STEP 2, define macro related to the spi bus
 *                 such as     #define BSP_USING_SPI1
 *
 * STEP 3, copy your spi init function from stm32xxxx_hal_msp.c generated by stm32cubemx to the end of board.c file
 *                 such as     void HAL_SPI_MspInit(SPI_HandleTypeDef* hspi)
 *
 * STEP 4, modify your stm32xxxx_hal_config.h file to support spi peripherals. define macro related to the peripherals
 *                 such as     #define HAL_SPI_MODULE_ENABLED
 */

/*#define BSP_USING_SPI1*/
/*#define BSP_USING_SPI2*/
/*#define BSP_USING_SPI3*/

/*-------------------------- SPI CONFIG END --------------------------*/

/*-------------------------- QSPI CONFIG BEGIN --------------------------*/
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

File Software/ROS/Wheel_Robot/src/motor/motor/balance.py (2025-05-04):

import rclpy, math, time, odrive
from rclpy.node import Node
from sensor_msgs.msg import Imu
from geometry_msgs.msg import Twist
from odrive.enums import *
from odrive.rich_text import RichText, Color, Style
import tf_transformations as tf
import numpy as np
import skfuzzy as fuzz
import skfuzzy.control as ctrl

class KalmanFilter:
    def __init__(self):
        self.dt = 0.01  # 采样时间
        # 状态变量 [角度, 角速度]
        self.x = np.array([[0], [0]])
        # 状态转移矩阵
        self.A = np.array([[1, -self.dt], [0, 1]])
        # 控制矩阵
        self.B = np.array([[self.dt], [1]])
        # 观测矩阵
        self.H = np.array([[1, 0]])
        # 过程噪声
        self.Q = np.array([[0.001, 0], [0, 0.003]])
        # 观测噪声
        self.R = np.array([[0.03]])
        # 误差协方差
        self.P = np.eye(2)

    def update(self, gyro, accel_angle):
        # 预测步骤
        u = np.array([[gyro]])  # 角速度输入
        x_pred = self.A @ self.x + self.B @ u
        P_pred = self.A @ self.P @ self.A.T + self.Q

        # 观测更新
        z = np.array([[accel_angle]])  # 加速度计计算的角度
        y = z - (self.H @ x_pred)  # 残差
        S = self.H @ P_pred @ self.H.T + self.R
        K = P_pred @ self.H.T @ np.linalg.inv(S)  # 卡尔曼增益

        # 更新状态
        self.x = x_pred + K @ y
        self.P = (np.eye(2) - K @ self.H) @ P_pred

        return self.x[0, 0]  # 返回估计角度


class IMUProcessor:
    def __init__(self):
        self.alpha = 0.98  # 互补滤波系数
        self.dt = 0.01  # 采样周期
        self.roll = 0.0
        self.pitch = 0.0

    def update(self, accel, gyro):
        # 加速度计计算角度（适用于低频、长期稳定）
        accel_roll = math.atan2(accel[1], accel[2])
        accel_pitch = math.atan2(-accel[0], math.sqrt(accel[1]**2 + accel[2]**2))

        # 陀螺仪积分计算角度（短期稳定，易漂移）
        gyro_roll = self.roll + gyro[0] * self.dt
        gyro_pitch = self.pitch + gyro[1] * self.dt

        # 互补滤波
        self.roll = self.alpha * gyro_roll + (1 - self.alpha) * accel_roll
        self.pitch = self.alpha * gyro_pitch + (1 - self.alpha) * accel_pitch

        return self.roll, self.pitch


class BalanceBot(Node):
    def __init__(self):
        super().__init__('balance_bot')

        # 初始化订阅
        self.imu_sub = self.create_subscription(Imu, 'imu', self.imu_callback, 10)
        self.cmd_vel_sub = self.create_subscription(Twist, 'cmd_vel', self.cmd_vel_callback, 10)

        # 连接Odrive
        try:
            self.odrive = odrive.find_any(timeout=10)
            self.get_logger().info("\033[32mOdrive Connected...\033[0m")
            self.odrive_setup()
            self.get_logger().info("\033[32mMotor Setup Successed...\033[0m")
            self.set_servo_angle(15, 15)
        except Exception as e:
            self.get_logger().error(f"error: {str(e)}")
            raise

        # 控制参数
        self.balance_kp = 30.0
        self.balance_ki = 1
        self.balance_kd = 1
        self.velocity_kp = 5
        self.velocity_ki = 0
        self.velocity_kd = 0

        # 目标角度
        self.target_roll = 0
        self.target_pitch = -0.04
        # 上次回调时间
        self.last_callback_time = time.time()
        self.last_time = time.time()
        # 误差项
        self.prev_error = 0.0
        self.integral = 0.0
        # 运动参数
        self.target_linear = 0.0
        self.target_angular = 0.0
        self.wheel_base = 0.174    # 车轮间距 (meters)
        self.wheel_radius = 0.026  # 轮子半径 (meters)
        # 初始化模糊控制器
        self.fuzzy_enable = False
        if self.fuzzy_enable:
            self.setup_fuzzy_controller()

        self.pitch_max = 0.4832998220
        self.pitch_min = -0.6481068829
        self.pitch_mid = (self.pitch_max + self.pitch_min) / 2
        self.max_speed = 50.0  # 电机最大转速 (rad/s)
        self.max_angle = 90.0  #
        self.min_angle = 0.0  #

        self.max_samples = 1000    # 启动时采样 1000 次
        self.pitch_sum = 0
        self.sample_count = 0
        self.calibration_complete = True

        self.imu_processor = IMUProcessor()
        self.kf_roll = KalmanFilter()
        self.kf_pitch = KalmanFilter()

        # 安全定时器
        # self.create_timer(0.1, self.safety_check)
        # self.last_callback_time = time.time()

    def safety_check(self):
        if time.time() - self.last_callback_time > 0.2:
            self.emergency_stop()

    def emergency_stop(self):
        self.odrive.axis0.controller.input_vel = 0.0
        self.odrive.axis1.controller.input_vel = 0.0
        self.get_logger().warn("紧急停止激活")

    def setup_fuzzy_controller(self):
        """ 设置模糊逻辑控制器 """
        # 定义模糊变量
        self.error = ctrl.Antecedent(np.arange(-0.03, 0.03, 0.001), 'error')
        self.d_error = ctrl.Antecedent(np.arange(-0.1, 0.1, 0.001), 'd_error')
        self.pid_output = ctrl.Consequent(np.arange(-1, 1, 0.001), 'pid_output')

        # 隶属函数
        self.error.automf(5)
        self.d_error.automf(5)
        self.pid_output.automf(5)
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

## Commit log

2025-03-18 update models
    [Case - Arm1-1-1.STL, Case - Arm1-2-1.STL, Case - Arm2-1-1.STL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]
2025-03-18 ros2 update
    [Base_Link.STL, IMU_Link.STL, Left_Wheel_Link.STL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]
2025-03-19 motor config
    [PM3510.xlsx]
2025-03-19 ROS odrive update
2025-03-20 modified: Software/Firmware/Freertos/.vscode/launch.json modified: Software/Firmware/Freertos/.vscode/settings.json new file: Software/Firmware/Freertos/Board/v3/FOC.ioc deleted: Software/Firmware/Fr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
2025-03-21 model refine
    [Case - Arm1-1-1.STL, Case - Arm1-1.STL, Case - Arm1-2-1.STL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]
2025-03-21 Modify power supply
2025-03-22 servo motor protocol
2025-03-22 servo protocol modifications
2025-03-24 motor conifgration
2025-03-26 servo init
2025-03-30 servo ctrl update
2025-04-01 odrive pid ctrl
2025-04-01 ROS update
    [wheel_robot.urdf]
2025-04-02 ROS Cartogarpher Setup
    [Wheel_Robot_Sim_With_Caster.csv, Wheel_Robot_Sim_With_Caster.urdf, base_link.STL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]
2025-04-02 Raspberry Adopt
2025-04-13 PCB document update
    [PM3510.xlsx]
2025-04-14 flowchart update
